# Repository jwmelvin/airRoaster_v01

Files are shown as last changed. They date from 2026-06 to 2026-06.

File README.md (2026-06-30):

# airRoaster

ESP32-based controller for a hot-air coffee roaster. Controls a heating element and fan independently via two [RBDimmer DimmerLink](https://www.rbdimmer.com/docs/dimmerlink-I2CCommunication) I2C AC dimmers, with a WebSocket interface for remote control and an OLED display for local status.

---

## Hardware

| Component | Details |
|---|---|
| MCU | ESP32-S3 Feather with 4MB Flash 2MB PSRAM, https://www.adafruit.com/product/5477 (any ESP32 variant with I2C and WiFi) |
| Display | FeatherWing OLED - 128x64 OLED, https://www.adafruit.com/product/4650 (SH1107 64×128 OLED), I2C address `0x3C` |
| Dimmer interface | RBDimmer DimmerLink, https://www.rbdimmer.com/docs/dimmerlink-overview, I2C address heat: `0x51`; fan: `0x52`, curve is set to mode `1` at startup. |
| Dimmers |Dimmers purchased from RobotDyn Official Store on AliExpress. "Dimmer AC module High Power for 40A 600V High Load, 1 Channel, 3.3V/5V logic"; "Dimmer AC module for 16A/24A 600V High Load, 1 Channel, 3.3V/5V logic with current load control" |
| Heater | from sdm2020_tools on eBay and listed as "1 set 230V 3600W 132.387 Heating Element & mica casing for hot air blower guns". Its power in my use is a little higher because I use 240V.|
| Blower | Ametek 116392-00 |

---

## Configuration

### WiFi credentials

Copy the credentials template and fill in your network details. This file is gitignored and should never be committed.

```
cp secrets.h.example secrets.h   # edit WIFI_SSID and WIFI_PASS
```

If `secrets.h.example` does not exist yet, create `secrets.h` manually:

```cpp
#pragma once
#define WIFI_SSID   "your_ssid"
#define WIFI_PASS   "your_password"
```

### Compile-time constants

| Constant | Default | Description |
|---|---|---|
| `DUTY_STEP` | `5` | Increment/decrement step for UP/DOWN commands (%) |
| `WS_PORT` | `81` | WebSocket server port |
| `DL_INIT_RETRY_DELAY_MS` | `500` | Delay between DimmerLink ready-check retries at startup (ms) |
| `IL_FAN_MIN` | `23` | Fan level below which heat is always 0 (both interlock modes) |
| `IL_FAN_FULL` | `30` | Fan level at or above which heat is fully unrestricted (soft mode) |
| `IL_HEAT_AT_MIN` | `30` | Heat cap (%) when fan is exactly at `IL_FAN_MIN` (soft mode) |

---

## Startup sequence

1. Display and I2C bus initialize
2. Both DimmerLink devices initialize — retried up to 3 times each (`DL_INIT_RETRY_DELAY_MS` apart); failures are logged. Dimmer init happens before WiFi to avoid missing the ready window at power-on.
3. ESP32 connects to WiFi (blocks until connected)
4. WebSocket server starts on port `81`
5. IP address is shown on the display

---

## Interfaces

### WebSocket (`ws://<device-ip>:81`)

The controller speaks two protocols on the same connection:

#### Artisan protocol (request/response)

Artisan polls the device on its sample interval. The controller responds with the current temperature readings.

**Request** (sent by Artisan):
```json
{"command": "getData", "id": 12345, "machine": 0}
```

**Response** (sent by controller):
```json
{"id": 12345, "data": {"BT": 195.3, "ET": 210.0}}
```

`BT` and `ET` are currently stubbed at `0.0` pending sensor integration. When sensors are added, populate the `btTemp` and `etTemp` globals in the firmware.

#### Plain-text commands

Artisan sliders and any other client send plain-text commands. Token delimiters are space, comma, semicolon, or equals sign. Commands are case-insensitive.

| Command | Example | Description |
|---|---|---|
| `OT1 <value>` | `OT1 60` | Set heat level (0–100%) |
| `OT1 UP` | `OT1 UP` | Increase heat by `DUTY_STEP` |
| `OT1 DOWN` | `OT1 DOWN` | Decrease heat by `DUTY_STEP` |
| `OT2 <value>` | `OT2 50` | Set fan level (0–100%) |
| `OT2 UP` | `OT2 UP` | Increase fan by `DUTY_STEP` |
| `OT2 DOWN` | `OT2 DOWN` | Decrease fan by `DUTY_STEP` |
| `INLET <degC>` | `INLET 165` | Set inlet setpoint and engage closed-loop control (see [Inlet temperature control](#inlet-temperature-control)) |
| `INLET OFF` | `INLET OFF` | Disengage closed-loop control; heat holds at its current level |
| `PID` | `PID` | Report current PID gains, setpoint, and mode |
| `PID <kp ki kd>` | `PID 1.5 0.05 0` | Set PID gains live (for manual tuning) |
| `TUNE` | `TUNE` | Run an open-loop step test and suggest PI gains (see [Tuning](#tuning)) |
| `TUNE <pct>` | `TUNE 20` | Step test with a specific heat step (% points) |
| `TUNE ABORT` | `TUNE ABORT` | Cancel a running step test |
| `TUNE APPLY` | `TUNE APPLY` | Apply the last test's "tight" suggested gains |
| `FF` | `FF` | Report feedforward params and current value (see [Feedforward](#feedforward-airflow-compensation)) |
| `FF <k>` | `FF 0.0045` | Set the feedforward coefficient `ffK` directly |
| `FF AMB <degC>` | `FF AMB 24` | Set the ambient reference temperature |
| `FF CAL` | `FF CAL` | Auto-calibrate `ffK` from the current (steady) operating point |
| `FF OFF` | `FF OFF` | Disable feedforward (`ffK = 0`) |
| `STAT` | `STAT` | Report and reset the control-cadence jitter watch (worst late-fire, µs) |
| `IL` | `IL` | Toggle interlock mode between hard and soft (see [Fan interlock](#fan-interlock)) |
| `LOG` | `LOG` | Retrieve the error log (sent only to requesting client) |

Sending `OT1 <value>` (manual heat) at any time is an **instant override**: it
drops the controller out of closed-loop mode and applies the manual level.

All unsolicited messages use Artisan's push message envelope so any client can use a consistent format:

**Status broadcast** (sent to all clients on any state change, and to new clients on connect):

```json
{"pushMessage": "status", "data": {"heat": 60, "heatReq": 60, "fan": 50, "ilCap": 100, "ilSoft": false, "mode": "manual", "inSV": 0.0}}
```

| `data` field | Description |
|---|---|
| `heat` | Actual heat level applied to the dimmer (%) |
| `heatReq` | Requested heat level before interlock (%) |
| `fan` | Fan level (%) |
| `ilCap` | Current heat ceiling imposed by the interlock (0–100%); `0` means heat is fully blocked, `100` means unrestricted |
| `ilSoft` | `true` if soft (linear) interlock mode is active; `false` for hard (binary) mode |
| `mode` | `"manual"` (heat set directly by `OT1`), `"inlet"` (heat modulated by the closed loop), or `"tune"` (a step test is running) |
| `inSV` | Inlet setpoint (°C) in use when `mode` is `"inlet"` |

**Error broadcast** (sent to all clients when an error is logged):

```json
{"pushMessage": "error", "data": "DimmerLink 0x51 ERR_PARAM (0xFE)"}
```

**Log response** (sent only to the client that sent `LOG`):

```json
{"pushMessage": "log", "data": "DimmerLink 0x52 not ready after 3 tries"}
{"pushMessage": "log", "data": "no errors"}
```

### Serial (115200 baud)

Accepts the same command set as WebSocket, terminated by newline. Maximum command length is 32 bytes. `LOG` prints the error log to Serial, one entry per line prefixed with `[LOG]`.

---

## Fan interlock

The interlock prevents the heating element from running without adequate airflow. It is always active and has two modes, toggled with the `IL` command (default: hard).

### Hard mode (default)

Binary cutoff: heat is forced to `0` when `fan < IL_FAN_MIN`, and fully unrestricted otherwise.

### Soft mode

Linear ramp between two breakpoints:

| Fan level | Heat cap |
|---|---|
| `< IL_FAN_MIN` (23) | 0% (blocked) |
| `IL_FAN_MIN` (23) | `IL_HEAT_AT_MIN` (30%) |
| `IL_FAN_FULL` (30) | 100% (unrestricted) |
| `> IL_FAN_FULL` | 100% |

Between 23 and 30 the cap is interpolated linearly, so heat scales with airflow rather than snapping on at a threshold.

In both modes:
- `heatReq` tracks what the user commanded
- `heat` reflects what is actually applied after capping
- Heat adjusts automatically whenever the fan level changes
- The interlock is re-evaluated every loop iteration

---

## Inlet temperature control

The controller can hold a target **inlet** temperature itself, closing the loop
on-device instead of relying on Artisan's 1 Hz command cycle. This is a
switchable mode layered on top of manual heat control.

### Modes

| Mode | How heat is set |
|---|---|
| `manual` (default) | Heat is whatever `OT1` last commanded |
| `inlet` | Heat is modulated by a PI(D) loop to hold the inlet setpoint |

- `INLET <degC>` engages `inlet` mode (bumpless — no heat step on engage) and
  sets the setpoint. Sending `INLET` again just retargets the setpoint and keeps
  the integrator, so a gradually-changing setpoint during a roast (e.g. driven
  from an Artisan background profile) does not reset the loop.
- `INLET OFF` returns to `manual`, holding heat at its current level.
- `OT1 <value>` is an instant manual override (drops back to `manual`).

### Control law

`controlStep()` runs on a fixed cadence (`CONTROL_PERIOD_MS`, default 250 ms)
from the main loop. The law is intentionally isolated in that one function
operating on shared globals — the *seam* that lets it move to a dedicated
FreeRTOS task later without changing the math (see `work.md`). It is currently
**cooperative** (single-core): adequate for a thermal plant with tens-of-seconds
time constants, and free of the cross-core I²C/SPI bus contention a dedicated
control task would introduce. The `STAT` command reports the worst observed
control-step timing jitter as evidence on whether a dedicated core is ever
warranted.

Key properties:
- **Derivative on measurement** (no setpoint-change kick), low-pass filtered.
- **Back-calculation anti-windup** against the *actually applied* heat — i.e.
  post-interlock — so the fan interlock capping heat does not wind up the
  integrator.
- Starts **PI-only** (`Kd = 0`); the inlet thermocouple is noisy near the
  dimmers (see [hardware/emi.md](hardware/emi.md)), so derivative is added only
  after the plant is characterized.

### Tuning

> ⚠️ The default gains (`pidKp`/`pidKi`/`pidKd` in the firmware) are **untuned
> placeholders** and are not expected to control well. Characterize the plant
> with `TUNE` (below) and apply gains before relying on closed-loop control.

- `PID` reports the current gains, setpoint, and mode.
- `PID <kp> <ki> <kd>` sets the gains live over WebSocket/serial, so you can tune
  without recompiling.

#### Autotune (`TUNE`)

`TUNE` runs an **open-loop step test**: it holds the current heat to measure a
baseline inlet temperature, applies a heat step, records the response, fits a
first-order-plus-dead-time (FOPDT) model (two-point 28.3%/63.2% method), and
suggests PI gains via the SIMC rule at two robustness levels.

**Procedure**

1. Set the fan to a representative level (your normal roasting range) and a
   moderate heat, and let the inlet temperature settle.
2. Send `TUNE` (default step) or `TUNE <pct>` (e.g. `TUNE 20`). The display shows
   `Tuning...` and `mode` becomes `tune`.
3. The test holds baseline (~8 s), steps heat up, and watches until the response
   flattens (or a 180 s cap). Heat returns to baseline and mode returns to
   `manual` automatically.
4. The result is broadcast as a `tune` push message:
   ```json
   {"pushMessage":"tune","data":{"ok":true,"fan":57,"step":15,"dT":42.3,
     "Kp":2.82,"tau":18.5,"theta":3.2,
     "tight":{"kp":1.97,"ki":0.13},"cons":{"kp":0.79,"ki":0.05}}}
   ```
   - `Kp` (°C/%), `tau`, `theta` (s) are the identified plant model.
   - `tight` is the brisker suggestion (tracking-first); `cons` is more
     conservative. Start with `tight`, fall back to `cons` if it overshoots or
     oscillates.
5. Apply gains with `TUNE APPLY` (uses the `tight` set) or `PID <kp> <ki> <kd>`
   to enter a chosen pair manually. Then `INLET <degC>` to run closed-loop.

**Safety / aborts.** The step goes through the fan interlock, so inadequate
airflow aborts the test (`interlock capped step`). It also aborts on over-temp
(`> 280 °C` inlet) and on any `OT1`/`INLET`/`TUNE ABORT`. A failed fit reports
`{"ok":false,"reason":...}`.

Because plant gain and time constant vary with airflow, run `TUNE` at the center
of your fan range (~57). The feedforward below — not the PID gains — is the main
mechanism for robustness against airflow changes.

### Feedforward (airflow compensation)

Steady-state heater power scales with airflow × temperature rise, so the
controller adds a feedforward term:

```
heat_ff = ffK · fan · (SV − ambient)
```

summed into the control output. The PID then only has to trim the residual. The
payoff is **airflow rejection**: when the fan changes mid-roast, `heat_ff` moves
*immediately* in proportion, instead of waiting for the inlet temperature to
drift and the integrator to catch up. One coefficient covers the narrow fan band.

Feedforward is **off by default** (`ffK = 0`). To set it up:

1. Stabilize the roaster in closed loop (or manual) at a representative fan and
   inlet temperature.
2. Send `FF AMB <degC>` with your ambient temperature (once), then `FF CAL`. This
   derives `ffK` from the current operating point:
   `ffK = heat / (fan · (inlet − ambient))`.
3. `FF` reports the result; `FF <k>` sets the coefficient by hand; `FF OFF`
   disables it.

With feedforward calibrated, the integrator settles near zero and the loop
rejects fan-speed changes largely through the feedforward path. Reported as an
`ff` push message: `{"ffK":0.00451,"amb":24.0,"ff":38.7}`.

---

## Commissioning

Bring the controller up in this order. Every step after the flash is a command
sent over WebSocket — the console page at [artisan/dashboard.html](artisan/dashboard.html)
has a **Commissioning sequence** panel that walks these steps with the value
fields prefilled.

1. **Flash.** With the board connected, run `./verify.sh upload` on the host.
2. **Sanity.** Stay in `manual`; confirm sensors, OLED, and Artisan still behave.
   After a few minutes send `STAT` to read control-cadence jitter — this is the
   evidence on whether the cooperative single-core design holds (expect
   single-digit ms).
3. **Characterize.** Set the fan to the center of your range (`OT2 57`) and a
   moderate heat (`OT1 40`), let the inlet temperature settle, then run `TUNE`.
   Eyeball the reported `dT`/`Kp`/`tau`/`theta` for sanity.
4. **Apply gains.** `TUNE APPLY` uses the `tight` suggestion; if it looks twitchy,
   enter the `cons` set by hand with `PID <kp> <ki> <kd>`.
5. **Calibrate feedforward.** Still steady, send `FF AMB <ambient>` then `FF CAL`.
6. **Close the loop.** `INLET <degC>` near the current inlet temp (bumpless), then
   nudge the setpoint and watch tracking.
7. **The real test.** With the loop holding, deliberately change fan speed and
   confirm the inlet temperature barely moves — that is the feedforward earning
   its keep. Tune gains from there.

## OLED display layout

```
+--------------------------------+
|  airRoaster vX.Y.Z             |  ROW1 (firmware version)
|  Heat: 60        Req: 60       |  ROW2
|  Fan: 50                       |  ROW3
|  IL:H ok                       |  ROW4 (interlock status — see below)
|  Inlet SV:165                  |  ROW5 ("Inlet: off" in manual mode)
|  192.168.1.42                  |  ROW6 (IP address or "No WiFi")
|                                |  ROW7
|  B:198.4 E:212.0 I:264.1       |  ROW8 (BT / ET / inlet temps, °C)
+--------------------------------+
```

ROW4 interlock status values:

| Display | Meaning |
|---|---|
| `IL:H ok` | Hard mode, fan above threshold, heat unrestricted |
| `IL:S ok` | Soft mode, fan above `IL_FAN_FULL`, heat unrestricted |
| `IL:S cap=N%` | Soft mode, fan in ramp zone, heat capped at N% |
| `IL:H BLOCKED` | Hard mode, fan below `IL_FAN_MIN`, heat forced to 0 |
| `IL:S BLOCKED` | Soft mode, fan below `IL_FAN_MIN`, heat forced to 0 |

---

## Error logging

Errors are stored in a RAM-only circular buffer (8 entries × 64 chars). No flash writes are performed. The log is lost on reboot.

Errors are generated for:
- DimmerLink not ready at startup (after 3 retries)
- DimmerLink error register non-zero after a write (`ERR_SYNTAX`, `ERR_NOT_READY`, `ERR_INDEX`, `ERR_PARAM`, or unknown code)
- DimmerLink error register polled every 5 seconds during operation

Retrieve the log at any time by sending `LOG` over WebSocket.

---

## Artisan integration

A ready-to-import Artisan settings file is provided at `artisan/airRoaster.aset` in this repo.

**Before importing**, open the file in a text editor and replace `<device-ip>` with your ESP32's IP address (shown on the OLED at startup). Then import via **File › Load Settings** in Artisan.

| Artisan setting | Value |
|---|---|
| Device | WebSocket (id 111) |
| Host | your ESP32's IP |
| Port | 81 |
| Input 1 → BT | `BT` node — bean RTD (the connected probe) |
| Input 2 → ET | `ET` node — second RTD (no probe yet; reads ~0) |
| Input 3 → IN | `IN` node — inlet thermocouple |
| Slider 0 | Fan — sends `OT2;<value>` |
| Slider 1 | Heat — sends `OT1;<value>` |

**Configuring the WebSocket inputs.** In Artisan, under **Config › Port ›
WebSocket**, set the input node names to match the firmware's JSON fields:
**Input 1: `BT`, Input 2: `ET`, Input 3: `IN`** (i.e. `channel_nodes=BT, ET, IN`
in the `.aset`). The node names just select which JSON field feeds each curve.

If a channel reads 0 °C / 32 °F while live data appears on a *different* curve,
the cause is almost always the **firmware** reading the wrong board for that
channel — confirm `CS_RTD_BT` points at the MAX31865 the bean probe is actually
wired to (see [hardware/pins.md](hardware/pins.md)). It is *not* an Artisan
channel-order issue.

The `ET` channel returns `0.0` until a second RTD probe is wired and
`RTD_ET_ENABLED` is set to `1` in the firmware.

### Adding more sensors

Artisan supports up to 10 channels via WebSocket: 2 on the main device plus 2 per extra device (max 4 extra devices), all pointing at the same `ws://<device-ip>:81`. The 10-channel ceiling is a total across the main device and all extra devices combined.

**To add channels** (firmware):
1. Add a global float for the new sensor
2. Extend the `data` object in `handleArtisanRequest()`:
   ```cpp
   snprintf(buf, sizeof(buf),
            "{\"id\":%s,\"data\":{\"BT\":%.1f,\"ET\":%.1f,\"inlet\":%.1f}}",
            idStr, btTemp, etTemp, inletTemp);
   ```

**To expose new channels in Artisan** (up to 10 total):
- For the first 2 channels beyond BT/ET, add node names to `channel_nodes` in the main device's `.aset` entry
- For additional pairs, add WebSocket extra devices in Artisan pointing at the same `ws://<device-ip>:81`, each with its own `channel_nodes` pair — they connect as additional clients and `handleArtisanRequest()` serves them all from the same `data` object with no firmware changes needed

**Beyond 10 channels:** a second WebSocket server on a different port would be required, as Artisan's framework caps at 10 channels per connection group.

---

## Dependencies

Install via Arduino Library Manager:

- [Adafruit GFX Library](https://github.com/adafruit/Adafruit-GFX-Library)
- [Adafruit SH110X](https://github.com/adafruit/Adafruit_SH110x)
- [WebSockets by Markus Sattler](https://github.com/Links2004/arduinoWebSockets)

---

## License

MIT — see [LICENSE](LICENSE).

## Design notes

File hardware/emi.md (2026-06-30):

# EMI / Sensor Noise — diagnosis and mitigation

How the AC dimmers couple noise into the temperature sensors, what's been done
about it, and what's left. Referenced from the sensor code in
[`../airRoaster.ino`](../airRoaster.ino) (`serviceRtd()` and the
robust-read constants).

---

## TL;DR — priority actions

| # | Action | Side | Status |
|---|---|---|---|
| 1 | Firmware tolerance: glitch-reject, debounce, hold-last-good | software | **done** (v0.2.0) |
| 2 | VIN–GND decoupling at each MAX31865 board (10 nF + 100 nF) | sensor | **done** |
| 3 | RC filter (100 Ω + 10 nF) on each RTD lead | sensor | **done** (helps lead pickup, not the reference path) |
| 4 | Twist each dimmer→load pair (line + return together) | source | **done** |
| 5 | Foil + copper-mesh shield on load runs, single-end grounded at enclosure | source | **done** |
| 6 | Dedicated earth bond to roaster body / enclosure (0.2 Ω) | grounding | **done** (was ~2 Ω) |
| 7 | Relocate 12→5 V converter below the divider | supply | **done** |
| 8 | Caps on R-78W output + input, and 5 V point-of-load (see below) | supply | **in progress** |
| 9 | SPI: shorten runs + 33 Ω series resistors at the Feather | sensor | **todo** |
| 10 | Clamp-on / toroid ferrite at the dimmer end of each load cable | source | **optional** |

The source-side and grounding work (4–7) is done. Remaining: finish the supply
decoupling (8) and tidy the SPI wiring (9), which is now the weakest link.

---

## Symptom

The connected PT1000 RTD (MAX31865) periodically stops reporting new values
during a roast and, before the firmware fix, would drop to 0 °C (= 32 °F in
Artisan). The K-type thermocouple (MAX31855) on the same SPI bus is unaffected.

Representative fault log (from `LOG` over WebSocket — see
[`../artisan/dashboard.html`](../artisan/dashboard.html)):

```
MAX31865 ET fault: 0x60   <- most common
MAX31865 ET fault: 0x64
MAX31865 BT fault: 0x08
```

A roast log (`airRoaster_14.alog`) showed the working RTD dropping out for
9–21 s at a time, several times between 3 and 7 minutes in.

---

## Fault-code decoding (MAX31865 fault register, 0x07)

| Bit | Mask | Meaning |
|-----|---|---|
| D7 | 0x80 | RTD resistance above High Fault Threshold |
| D6 | 0x40 | RTD resistance below Low Fault Threshold |
| D5 | 0x20 | REFIN− > 0.85 × VBIAS |
| D4 | 0x10 | REFIN− < 0.85 × VBIAS (FORCE− open) |
| D3 | 0x08 | RTDIN− < 0.85 × VBIAS (RTD− / FORCE− open) |
| D2 | 0x04 | Overvoltage / undervoltage on an analog input |

Observed:

- **`0x60` = D6 + D5** — low RTD reading **+ reference low-side (REFIN−) pulled high.**
- **`0x64` = D6 + D5 + D2** — same, **plus an input transient outside the valid window.**
- **`0x08` = D3** — RTD− effectively open. This came from the *unconnected*
  board (no probe); it is expected and is gated off in firmware. The single
  connected probe is the **BT** (bean) probe; the no-probe board is **ET** and is
  disabled via `RTD_ET_ENABLED`.

The **D2 bit in `0x64` is the tell**: it fires only when an input briefly swings
outside its valid range — the fingerprint of an *injected transient*, not a
steady wiring fault. And **D5 places the disturbance in the reference path**
(the 4300 Ω reference resistor / VBIAS network), which is *internal to the
board* — not on the probe leads.

---

## Diagnosis

**Key clue: the thermocouple never faults, but the RTD does.** If this were
generic SPI-bus corruption or a dirty 3.3 V/5 V rail, both SPI devices would
suffer. They don't. That rules out "the whole bus is noisy" and points at what
makes the MAX31865 different:

1. It makes a **ratiometric** measurement against VBIAS through a tiny bias
   current. Disturb VBIAS or the reference divider and the reading moves.
2. It runs **analog fault comparators** (REFIN−, RTDIN−, over/under-voltage)
   continuously. A fast transient can trip a comparator mid-conversion even when
   the underlying ADC value would have been fine.

The phase-cutting dimmers (TRIAC fires partway through each mains half-cycle)
emit sharp broadband transients twice per cycle. These couple into wiring by
both magnetic (di/dt through load-wire loop area) and electric (dv/dt) fields.
The MAX31865's reference circuit is the susceptible victim.

**Not correlated with heat level** — confirmed in testing. That fits, because
the **fan dimmer runs continuously** through a roast (same RBDimmer module),
so its transients are present regardless of the heater setting. Both dimmers
are equal suspects; don't fixate on the heater.

### Why the lead RC filters didn't fully fix it

The 100 Ω + 10 nF filters on the RTD **leads** address pickup on the RTD wires
(the RTDIN path). But the dominant `0x60`/`0x64` faults are in the **REFIN /
VBIAS** path, which is on the board and not reachable from the leads. So the
lead RC is correct and worth keeping (it protects against RTDIN-side faults and
helps the open-lead case), but it cannot suppress the reference-path noise — which
is why dropouts persisted after adding it.

### Note on the 50/60 Hz notch filter

The MAX31865 has a selectable 50/60 Hz notch (Adafruit library default 60 Hz,
correct for US mains). It rejects *mains-frequency* pickup but **not** the
broadband dimmer-edge transients, so it is not the fix here — but it is set
correctly and should stay at 60 Hz.

---

## What's been done

### Software (v0.2.0)

`serviceRtd()` in [`../airRoaster.ino`](../airRoaster.ino) makes the
read robust instead of trusting a single fault byte:

- **Same-cycle glitch rejection** — two reads per cycle; if they disagree by
  more than `RTD_READ_DISAGREE_C` (2 °C) the SPI frame was likely corrupted, so
  the value is held and retried next cycle.
- **Plausibility window** — a reading is accepted only if it falls between
  `RTD_VALID_MIN_C` (−20 °C) and `RTD_VALID_MAX_C` (600 °C); a transient fault
  flag on an otherwise in-range value is ignored.
- **Debounce** — a channel is only declared faulted after `SENSOR_FAULT_DEBOUNCE`
  (4) consecutive bad reads, so brief transients don't blank the curve.
- **Hold-last-good** — during a fault the global keeps its last valid value
  rather than dropping to 0 °C, so Artisan sees a momentary hold (much better for
  the curve and RoR than a spike to 32 °F).
- **Converter recovery** — `clearFault()` is followed by re-enabling bias and
  auto-convert (clearing the fault resets config bits, which would otherwise stop
  conversions).
- **Rate-limited logging** — repeated faults are logged at most every
  `SENSOR_REFAULT_LOG_MS` (5 s) so the 8-entry error log isn't flooded.

This makes the channel ride through brief EMI events regardless of source, but it
is *tolerance*, not a cure — the hardware items below reduce the events
themselves.

### Hardware (sensor side)

- **VIN–GND decoupling** at each MAX31865 board input — 10 nF + 100 nF,
  stiffening the supply feeding VBIAS.
- **RC filter** (100 Ω series + 10 nF to GND) on each RTD lead — two per board,
  on RTD+ and RTD−. RC ≈ 1 µs, well inside the MAX31865's tolerance.

### Hardware (source + grounding + supply)

- **Twisted load pairs** — each dimmer→load line+return twisted together to
  collapse loop area (magnetic emission).
- **Foil + copper-mesh shield** over the load runs, **single-end grounded at the
  enclosure** (stops short of the grounded roaster body to avoid a ground loop;
  see §3 under *Source suppression* for the foil+mesh and single-end rationale).
- **Dedicated earth bond** added — roaster body / enclosure to incoming earth is
  now **0.2 Ω** (was ~2 Ω). Improves both fault safety and the shield's ground
  reference.
- **12→5 V converter (R-78W) relocated below the divider**, moving the switching
  node to the mains side; only the filtered 5 V now crosses to the sensors.

### Considered but not feasible

- **Cap directly across the reference resistor (REFIN+ / REFIN−)** would target
  the `0x60` path directly, but the SMD pads are too small/precise to add
  reliably by hand. Abandoned in favour of supply decoupling + source
  suppression.

---

## Capacitor summary

Consolidated list of every decoupling/filter cap in the system. The first three
rows are installed; the supply-rail rows are the remaining additions.

| Location | Caps | Purpose | Status |
|---|---|---|---|
| Each RTD lead → GND | 10 nF (+ 100 Ω series) | RTD-lead pickup filter (RTDIN path) | installed |
| Each MAX31865 VIN/3V3 → GND | 10 nF + 100 nF | board supply decoupling at VBIAS | installed |
| **R-78W 5 V output** | **100 µF electrolytic (low-ESR) + 100 nF ceramic** | absorb switching ripple at the source | add |
| **R-78W 12 V input** | **10 µF** | switcher input decoupling + stops switching current conducting back up the 12 V line | add |
| **5 V arrival, top side near Feather** | **47–100 µF bulk** | point-of-load; catches noise picked up crossing the divider | add |
| 3.3 V distribution node (optional) | 10 µF bulk | rounds out the 3.3 V rail (likely already covered by the Feather LDO) | optional |

Notes:
- Place the R-78W caps **as close to the converter pins as the terminal block
  allows** — lead length undoes the benefit.
- The 5 V point-of-load cap matters specifically because the converter now lives
  below the divider, so the 5 V output travels across to the sensors: filter hard
  at the source **and** again where it arrives.

## SPI wiring

The remaining weak link. The SPI bundle from the three breakouts to the Feather
is long and the signals aren't paired with grounds. **Caps are not the right tool
here** — capacitance on SPI lines rounds the edges and can hurt signal integrity
at the clock rate. Instead, in priority order:

1. **Shorten the runs** (SCK shortened already) and **twist each signal with a
   ground return**, or run the group flat against the grounded panel.
2. **33 Ω series resistors** on SCK / MOSI / MISO **at the Feather end** — damps
   ringing; the closest thing to a component-level fix.
3. The firmware glitch-rejection (v0.2.0) already tolerates the occasional
   corrupted frame, so the SPI wiring doesn't have to be perfect.

---

## Source suppression — reference

> **Status:** items 1, 3, and 6 below are **done** (twisted pairs, foil+mesh
> shield single-end grounded, dedicated 0.2 Ω earth bond). Ferrites (2), the
> blower brush caps (4), and the snubber (5) remain optional. Kept here as the
> technical reference for why each measure works.

The dimmer→fan and dimmer→heater load cables carry the phase-cut current and are
the primary emitters. Attacking the source helps every victim at once.

### 1. Twist each load pair — biggest free win

Radiated magnetic field is proportional to the **loop area** between the
outgoing conductor and its return. Route each load's line and neutral **together
as a tight pair and twist them**; this collapses the loop area and dramatically
cuts magnetic emission. Make sure the return actually runs alongside the switched
conductor rather than taking a separate path.

### 2. Ferrites on the load cables

Add a **clamp-on ferrite or toroid at the dimmer end of each load cable** (and
optionally where the cable exits the enclosure). Pass **both conductors of that
load through the same core** so the 60 Hz fields cancel and only the
high-frequency common-mode component is choked. A few turns through a toroid
beats a single pass-through clamp. Cheap, reversible, no effect on the 60 Hz
power.

### 3. Shield the external runs

Twisting handles the magnetic field; a grounded shield handles the electric
field. Do both.

**Foil + mesh (as built).** This is the standard foil-braid construction:
- **Foil** gives ~100 % coverage and closes the apertures for higher-frequency
  content. Overlap wraps ≥50 %. Watch for foil tape with *non-conductive*
  adhesive — only the exposed face conducts, so the mesh over it ties it together.
- **Copper mesh** provides the low-impedance ground-drain path and mechanical
  robustness foil lacks. **Fairly open mesh is fine** at the frequencies that
  matter here — the holes are tiny vs. wavelength, so E-field attenuation stays
  good. Multiple wraps raise effective coverage and lower shield resistance; two
  layers is plenty.
- Foil and mesh must be in **electrical contact** so they bond as one shield.

**Shield grounding — one end, at the enclosure (source).** The cable is
electrically short at these frequencies, so single-end termination gives
essentially full shielding without a floating-stub penalty, and it avoids a
ground loop between the enclosure earth and the **separately-grounded roaster
body**. Ground at the *source* (enclosure) end so intercepted noise current
returns near the dimmer. **Stop the shield just short of the body** and insulate
the floating end so it can't contact the body (which would sneak-ground the
second end) or a live conductor.

Alternatively, **shielded mains-rated cable** (e.g. SY/CY screened flex) or
**grounded metal conduit** achieves the same thing in one component.

### 4. Blower brush noise (separate source)

The Ametek 116392-00 is a brushed universal motor, so it generates its own
broadband RF from brush arcing, independent of the dimmer. Ferrites on the motor
leads (item 2) help. Motor-suppression X/Y caps across the brushes are the
classic fix but interact with the TRIAC dimmer — add cautiously, ferrites first.

### 5. Snubber across the dimmer output (advanced, optional)

An RC snubber (≈100 Ω + ~0.1 µF X-rated) across the dimmer output softens the
switching edge and reduces broadband emission. **Caveat:** the RBDimmer modules
may already include one; an added snubber passes a little leakage current when
"off" and can affect low-end dimming. Try the wiring measures first.

### 6. Grounding discipline — done

The enclosure/back-panel is **bonded to AC earth**, with a **dedicated bond now
at 0.2 Ω** (was ~2 Ω), and shields/panel return to a single earth point. HF
currents have a defined low-impedance path and don't circulate through signal
ground.

### Supply side — R-78W (RECOM R-78W-0.5)

The 12 V→5 V converter is a switching regulator (~500 kHz). It has been
**relocated below the divider**, so its switching node sits on the mains side and
only the filtered 5 V crosses to the sensors. Decoupling caps (output bulk +
ceramic, input cap, and a 5 V point-of-load cap up top) are listed in the
[Capacitor summary](#capacitor-summary) — those are the remaining additions.

---

## Layout reference

- Low-voltage section is above the white divider; mains below. Dimmers are lower
  left (below the divider). The R-78W now sits **below** the divider, so its
  switching node is on the mains side and only the **filtered 5 V crosses** the
  divider to the sensors.
- Keep sensor cables (especially the RTD leads) flat against the grounded panel,
  short, and crossing any AC wiring at 90° rather than running parallel.
- See [`pins.md`](pins.md) for the full pin/bus map.

---

## Diagnostic workflow

1. Open [`../artisan/dashboard.html`](../artisan/dashboard.html) in a browser, connect to the
   ESP32 IP, and watch the live `error`/`log` stream during a roast.
2. Note which channel (BT/ET) and which fault codes appear, and whether they
   correlate with fan level, heat level, or are constant.
3. Decode codes with the table above. REFIN/over-voltage bits (D5/D2) ⇒ reference
   path / injected transient ⇒ source suppression + supply decoupling. RTDIN/open
   bits (D3/D4) ⇒ check leads, terminals, and the RC filter on that leg.
4. After each mitigation, compare dropout frequency/duration in the Artisan
   `.alog` to gauge improvement.

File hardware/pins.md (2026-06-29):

# Pin Usage — ESP32-S3 Feather (Adafruit 5477)

Arduino variant file: `adafruit_feather_esp32s3`

---

## I2C bus

SDA = GPIO 3 (A6), SCL = GPIO 4 (A7)
Pull-ups: 5 kΩ on-board; also exposed on STEMMA QT connector.

| Address | Device | Product |
|---|---|---|
| `0x3C` | SH1107 OLED | Adafruit 4650 FeatherWing |
| `0x51` | DimmerLink — heat | RBDimmer DimmerLink |
| `0x52` | DimmerLink — fan | RBDimmer DimmerLink |
| TBD (`0x76` or `0x77`) | BME688 env sensor | Adafruit 5046 (future) |

The BME688 connects via the STEMMA QT port — no extra wiring needed.

---

## SPI bus

SCK = GPIO 36, MOSI = GPIO 35, MISO = GPIO 37

| GPIO | Feather label | Firmware define | Device | Role |
|---|---|---|---|---|
| 36 | SCK | — | shared | SPI clock |
| 35 | MOSI | — | shared | SPI data out |
| 37 | MISO | — | shared | SPI data in |
| 10 | D10 / A11 | `CS_RTD_BT` | MAX31865 (Adafruit 3648) | Bean temp PT1000 |
| 9 | D9 / A10 | `CS_RTD_ET` | MAX31865 (Adafruit 3648) | Exhaust/ET PT1000 |
| 8 | A5 | `CS_TC_IN` | MAX31855 (Adafruit 269) | Inlet K-type thermocouple |

---

## Reserved / do not use

| GPIO | Label | Reason |
|---|---|---|
| 3 | SDA / A6 | I2C in use |
| 4 | SCL / A7 | I2C in use |
| 7 | — | I2C power control (managed by board) |
| 13 | D13 | Built-in red LED |
| 21 | — | NeoPixel power enable |
| 33 | — | NeoPixel data |
| 35 | MOSI | SPI in use |
| 36 | SCK | SPI in use |
| 37 | MISO | SPI in use |

---

## Free GPIOs

| GPIO | Feather label |
|---|---|
| 5 | A8 |
| 6 | A9 |
| 11 | A12 |
| 12 | A13 |
| 14 | A4 |
| 15 | A3 |
| 16 | A2 |
| 17 | A1 |
| 18 | A0 |
| 38 | RX (Serial1) |
| 39 | TX (Serial1) |
| 42 | SS (default SPI SS, unused) |

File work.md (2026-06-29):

# Development plan

## inlet-temp control

### framing

The airRoaster now measures inlet temperature, which is a primary process variable. The current system relies on external commands to regulate the heater to maintain a desired inlet temperature. That suffers from the slower reporting cycle by which Artisan receives temperature updates and sends heater commands (1 Hz). Improvement (tighter control) can come from internalizing the control loop. It will also allow flexible control strategies that Artisan may not.

### objectives

Develop a switchable operating mode that accepts "inlet" commands to set the desired inlet temperature, and implements feedback control from the measured inlet temp to modulate the heater with the tightest possible control. The control strategy and tuning should prioritize robustness against flow variation (e.g., from external fan-speed changes). Generally, the inlet setpoint will change gradually during a roast, with large transitions happening only at the start of a roast. 

### design considerations

- as an initial gate, consider whether this change (or other project attributes) would favor moving from the Arduino environment to ESP-IDF (https://docs.espressif.com/projects/esp-idf/en/v6.0.1/esp32s3/index.html)

- one reason for that potential migration is that the microcontroller for this project, ESP32-S3, has dual cores and the temperature-measurement-and-control aspects might benefit from separating them from the interface (WiFi, websocket, and OLED) aspects. I do not know if Arduino supports dual-core implementations but ESP-IDF does.

### constraints

- Operate the control loop with deterministic timing.
- Branch the project so that work can progress on this new capability without disturbing the current code.
- 

### references

- PID library for Arduino environment: https://github.com/br3ttb/Arduino-PID-Library
-- author's explanations: http://brettbeauregard.com/blog/2011/04/improving-the-beginners-pid-introduction/
-- explanation of the library's POM mode:  http://brettbeauregard.com/blog/2017/06/introducing-proportional-on-measurement/
-- and: http://brettbeauregard.com/blog/2017/06/proportional-on-measurement-the-code/ 

---

## plan (2026-06-29)

Branch: `feature/inlet-control`. Planning only at this stage — no firmware
written yet.

### Gate decision 1 — stay in Arduino, do NOT migrate to ESP-IDF (yet)

The two reasons floated for ESP-IDF (deterministic timing, dual-core
separation) are both achievable *inside the Arduino-ESP32 core*, which is
itself a thin layer over ESP-IDF + FreeRTOS:

- **Dual core is already available.** The Arduino `loop()` runs as a FreeRTOS
  task (`loopTask`) pinned to core 1; core 0 runs the WiFi/BT stack. We can
  create our own control task with `xTaskCreatePinnedToCore()` — no migration
  required.
- **Deterministic cadence is already available.** A dedicated FreeRTOS task
  using `vTaskDelayUntil()` (fixed wake period, not `delay()`) at a raised
  priority gives a jitter-bounded loop independent of WebSocket/OLED work.

Against migration: a port would have to replace the whole interface stack that
already works — `WebSocketsServer` (Links2004), `Adafruit_SH110X`/`GFX`,
`Adafruit_MAX31865`/`MAX31855`, `WiFi`. That is weeks of yak-shaving for no
control benefit the Arduino core can't deliver. **Recommendation: keep Arduino;
revisit ESP-IDF only if we later hit a concrete wall (e.g. needing TLS, OTA at
scale, or sub-millisecond ISR-level timing the Arduino core obstructs).**

### Gate decision 2 — control library

Use **Dlloydev/QuickPID** for the controller and **Dlloydev/sTune** for
characterization/autotune (same author, designed to interoperate, both
ESP32-clean, actively maintained — unlike br3ttb's original which is feature-
frozen). QuickPID adds what we need over the original: selectable
Proportional-on-Error / Proportional-on-Measurement *blend* (per Beauregard's
POM articles), multiple anti-windup modes, and a TIMER mode that fits a
fixed-cadence FreeRTOS task. sTune's open-loop **s-curve inflection** test
identifies a first-order-plus-dead-time (FOPDT) model in ~½τ — ideal for a
thermal plant and the basis for an operator-runnable tuning routine.

References vetted: br3ttb library still works but is the wrong long-term choice;
QuickPID + sTune supersede it. (Kilill's ESP-IDF fork is only relevant if we
ever migrate.)

### Actuator note (simplifies everything)

The heater is a phase-cut AC dimmer that already accepts a **continuous 0–100
level** over I²C (`setLevel(HEAT_ADDR, …)`). So the PID output maps *directly*
to heat level — no time-proportioning relay/PWM layer needed. The control
output path is just: `pidOutput → requestedHeatLevel → applyInterlock() →
setLevel()`.

### Control strategy — robustness against flow variation is the design driver

Airflow (fan level, possibly changed externally mid-roast) changes BOTH the
plant gain and the time constant of inlet temperature vs. heat: more flow ⇒
lower steady inlet temp for the same power AND a faster, shorter-τ response.
A single fixed PID tuned at one flow will be sluggish or unstable at another.
Three layers, in priority order:

1. **Feedforward from a static power map** `heat_ff = f(setpoint, fan)`.
   Steady-state heater power needed scales ~linearly with mass-flow ×
   (T_set − T_ambient). A small calibrated map gives most of the command
   instantly when fan changes; the PID only trims the residual. This is the
   single biggest robustness win and largely neutralizes flow disturbances
   before the feedback loop has to react.
2. **Gain scheduling on fan level — conditional.** Because fan level is a
   *known* input, gains *can* be scheduled across fan breakpoints and
   interpolated. But the actual operating band is narrow (50–65, mostly 55–60;
   see Operator decisions), so a single tune at the center is the starting
   point and scheduling is added only if band-edge validation needs it.
3. **Robust feedback tuning (IMC / lambda).** Tune via Internal-Model-Control
   (lambda) rules rather than Ziegler-Nichols: λ is an explicit
   robustness/speed knob (λ ≈ θ for brisk, 2–3θ for conservative). Pick λ on
   the conservative side and validate gain margin at the worst-case (lowest-
   flow, highest-gain) point. Use **Proportional-on-Measurement-leaning blend**
   so the occasional large setpoint step (roast start) doesn't cause overshoot,
   while gradual setpoint moves during the roast stay tight.

Supporting details:
- **Anti-windup** is mandatory: heat saturates at 0/100 *and* the fan interlock
  can cap it below the PID's request. The integrator must be clamped/back-
  calculated against the **actually-applied** heat (post-interlock), not the
  requested value, or it winds up whenever the interlock bites.
- **Derivative** on the inlet thermocouple: derivative-on-measurement + light
  low-pass (the TC is fast but noisy near the dimmers — see hardware/emi.md).
  Start PI-only; add D only if sTune shows it helps.
- **Bumpless transfer**: on engaging inlet mode, seed the integrator with the
  current heat level so there's no step; on disengaging, leave heat as-is.

### Mode + command design

New switchable closed-loop mode layered on the existing manual path:
- `INLET <degC>` — set inlet setpoint AND engage closed-loop mode (bumpless).
- `INLET OFF` — disengage, hold last heat (manual).
- Sending `OT1 <value>` (manual heat) auto-disengages inlet mode — gives the
  operator an instant manual override with no extra command.
- `TUNE` (operator routine) — run an sTune open-loop step at the *current* fan
  level, report identified K/τ/θ + suggested gains over WebSocket/serial, and
  optionally store them into the gain-schedule slot for that fan band. Operator
  repeats at low/med/high fan to populate the schedule.
- Status broadcast gains: `mode` (manual|inlet), `inSV` (setpoint), and the
  inlet temp is already published as `IN`.

Artisan drives the setpoint via a background profile (see the utility below,
which generates an `.alog` whose background curve becomes the inlet SV) or a
dedicated slider/event mapped to the `INLET` command — mirroring how OT1/OT2
sliders work today.

### Concurrency / timing architecture

- **Core 1 (interface task = Arduino `loop()`):** WebSocket, OLED, command
  parsing, WiFi servicing — unchanged, non-deterministic is fine here.
- **Core 0 (new `controlTask`, pinned, raised priority, `vTaskDelayUntil`):**
  read inlet TC → run QuickPID (TIMER mode) → apply feedforward + gain schedule
  → write heat through the interlock. Fixed cadence ~5–10 Hz (the TC + thermal
  plant don't justify faster; deterministic period matters more than rate).
- **Shared state** (setpoint, mode, fan level, heat level, gains) guarded by a
  small mutex or made atomic. Keep the critical section tiny.
- The other sensors (BT/ET RTDs) and their robust-read logic can stay on the
  interface cadence or move into the control task; decide during implementation.

### Architecture decision (resolved 2026-06-29)

After working through the FreeRTOS dual-core option: **cooperative single-core**
for v1, with the control law isolated in a `controlStep()` *seam* (operates only
on shared globals) so it can later lift into a pinned task unchanged. Rationale:
the ESP32-S3 has two I2C controllers and a spare SPI, so a lock-free dual-core
partition *is* possible (heat dimmer on `Wire1`/control core; OLED+fan+all
sensors/SPI on the interface core; cross-core state as 32-bit-atomic scalars) —
but it needs a hardware rewire (heat dimmer → `Wire1`) in the EMI-sensitive zone
and the plant's tens-of-seconds time constants don't require sub-10 ms
determinism. `STAT` reports a control-cadence jitter watch as the evidence that
would justify migrating later.

Also decided to implement a **compact inline PID** rather than QuickPID for the
loop itself — it gives exact control over back-calculation anti-windup against
the *post-interlock* applied heat, with no dependency to install/compile here.
sTune is still the intended tool for the `TUNE` step-test routine (phase 3).

### Phased work

1. ~~Scaffolding: `controlStep()` seam, fixed-cadence call from `loop()`,
   jitter watch.~~ **done (v0.3.0)** — cooperative, not a task.
2. ~~Closed-loop PI(D) with back-calculation anti-windup against post-interlock
   heat; `INLET`/`INLET OFF`/`OT1`-override mode switching with bumpless
   transfer; `PID` live-tuning + `STAT` commands.~~ **done (v0.3.0)** — gains
   are untuned placeholders.
3. ~~`TUNE` routine (open-loop step test) + reporting; FOPDT fit + SIMC PI
   suggestions.~~ **done (v0.4.0)** — implemented inline (two-point FOPDT fit,
   SIMC tight/conservative gains) rather than with sTune, for full control over
   step safety/abort and to stay dependency-free + compile-checkable here.
   Operator still needs to run it at center fan (~57) and spot-check 50 / 65.
4. Feedforward power map (2–3 points across 50/57/65) + lambda/IMC gains from
   step (3); add gain scheduling only if band-edge validation needs it. **next**
5. Validation roasts: step + ramp setpoints, deliberate mid-roast fan changes;
   measure tracking/overshoot/settling and confirm robustness. Tune λ.
6. ~~Docs: README control-mode section.~~ **done (v0.3.0)** — Artisan
   integration + `.aset` for driving the setpoint still to do in phase 4.

### Operator decisions (resolved 2026-06-29)

1. **Overshoot tolerance is generous; tracking is the priority.** ~5 s at
   +10–20 °F (≈ +5.5–11 °C) overshoot at roast start is acceptable. What
   matters most is tight *tracking* during the roast and good rejection of
   airflow changes. → Tune on the **brisk** side (smaller λ, ≈ θ–1.5θ);
   prioritize setpoint tracking + flow-disturbance rejection over startup-step
   overshoot suppression. The generous startup tolerance means we do **not**
   need a heavy Proportional-on-Measurement bias to tame the opening step — a
   light POM blend or even proportional-on-error is fine. Validate on the
   tracking/disturbance metrics, not the startup step.
2. **Fan operates in a narrow band: 50–65, usually 55–60.** This is small
   enough that the plant gain/τ won't swing much across it, so **full gain
   scheduling is likely unnecessary.** Revised approach:
   - Identify the plant once with sTune at the **center (~57)**, and tune a
     single robust PID there.
   - Keep the **feedforward power map** anyway — it's what gives fast rejection
     of mid-roast airflow changes (the stated priority), and over a 50–65 span
     it's nearly linear so a 2–3 point map (50 / 57 / 65) suffices.
   - Add gain scheduling **only if** step (5) validation shows the single tune
     degrades at the band edges. Spot-check sTune at 50 and 65 to confirm the
     model barely moves before deciding.
3. **`OT1` is an instant manual override** — confirmed. Any `OT1 <value>`
   immediately disengages inlet mode and applies the manual heat level.

# utilities

## Artisan profile generator so a background can drive SV through Inlet control parameter

python3 make_inlet_background.py --out bkgnd_001-base_330-550_5.30.alog --mode ror_endpoint --no-mirror --template bkgnd_001-base.alog \
--t_drop 330 \
--T_start 350 --T_drop 500 \
--ror_start 50

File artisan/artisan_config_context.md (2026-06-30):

# Artisan Configuration Context — airRoaster

## Goal

Configure Artisan to:
1. Read BT and ET from two Phidget temperature modules on a networked HUB5000
2. Send fan and heat control commands to an ESP32 roaster controller over WebSocket

---

## Hardware

| Device | Role |
|---|---|
| ESP32 (airRoaster firmware) | Roaster controller — controls heat and fan via I2C AC dimmers |
| Phidget HUB5000 | VINT hub, networked at `192.168.1.232` (also reachable as `hub5000.local`) |
| Phidget TMP1200 on HUB VINT port 0 | RTD input, PT1000 probe → **BT (bean temperature)** |
| Phidget TMP1101 on HUB VINT port 1 | 4-channel thermocouple input, K-type probe on channel 0 → **ET (exhaust temperature)** |

---

## ESP32 WebSocket Interface

- URL: `ws://<esp32-ip>:81`
- The ESP32 IP is shown on its OLED display at startup.

### Polling (Artisan → ESP32)

Artisan sends on its sample interval:
```json
{"command": "getData", "id": 12345, "roasterID": 0}
```

ESP32 responds:
```json
{"id": 12345, "data": {"BT": 0.0, "ET": 0.0}}
```
BT and ET are currently stubbed at 0.0 — real values come from Phidgets (see below).

### Control commands (Artisan sliders → ESP32)

Slider actions use Artisan's WebSocket `send()` syntax:

| Slider | Action string | Effect |
|---|---|---|
| Fan | `send("OT2;{}")` | Sets fan level 0–100% |
| Heat | `send("OT1;{}")` | Sets heat level 0–100% |

The firmware also accepts `send({{"command":"OT2","value":{}}})` JSON envelope format — both work.

### Status broadcast (ESP32 → all clients, unsolicited)

```json
{"pushMessage": "status", "data": {"heat": 60, "heatReq": 60, "fan": 50, "ilCap": 100, "ilSoft": false}}
```

| Field | Description |
|---|---|
| `heat` | Actual heat level sent to dimmer (%) |
| `heatReq` | Requested heat level before interlock (%) |
| `fan` | Fan level (%) |
| `ilCap` | Current heat ceiling from interlock (0=blocked, 100=unrestricted) |
| `ilSoft` | `true` = soft (linear ramp) interlock; `false` = hard (binary) interlock |

---

## Key References

- Artisan WebSocket protocol: https://artisan-scope.org/devices/websockets/
- Artisan Phidgets configuration: https://artisan-roasterscope.blogspot.com/2017/12/more-phidgets.html
- HUB5000 + dual single-channel modules setup (home-barista forum, post #7 by Rob W):
  > Since each VINT module delivers only one channel but Artisan's main device expects two,
  > use an Extra Device for the second module and remap its channel to ET via the symbolic
  > formula `Y3` in the Symb ET/BT tab.

---

## Artisan Configuration Steps

### 1. Main device (Config → Device → 1st tab "ET/BT")

- **Meter**: `Phidget TMP1200`
  - This provides BT from VINT port 0, PT1000.
  - The ET slot will be filled via symbolic remap from the extra device (see step 4).

### 2. Phidgets tab (Config → Device → 4th tab "Phidgets")

- **TMP1200**: VINT port `0`, channel `0`, RTD type `PT1000`
- **Network**: ✓ ticked, host `192.168.1.232`, port `5661`

### 3. Extra Devices tab (Config → Device → Extra Devices)

Add **one extra device**:
- Type: `Phidget TMP1101 4xTC`
- VINT port `1`, channel `0`, thermocouple type `K`
- Untick **LCD and curve for channel 2** (TMP1101 returns only one signal here)
- Untick **LCD and curve for channel 1** (data will be remapped to ET — no need to display it separately)

Add **one more extra device** (for WebSocket slider control):
- Type: `WebSocket` pointed at `ws://<esp32-ip>:81`
- Untick LCD and curve for both channels (BT/ET from this device are stubbed at 0.0 and ignored)
- Sliders send via this connection

### 4. Symb ET/BT tab (Config → Device → 2nd tab)

- **ET Y(x)**: `Y3`

`Y3` is the symbolic variable for channel 1 of the first extra device (the TMP1101), routing its reading into the main device's ET slot.

### 5. Sliders (Config → Events → Sliders)

| Slider | Action type | Command |
|---|---|---|
| Slider 0 (Fan) | WebSocket | `send("OT2;{}")` |
| Slider 1 (Heat) | WebSocket | `send("OT1;{}")` |

Both sliders send over the WebSocket connection to the ESP32.

---

## Firmware Fan Interlock (informational)

The ESP32 firmware enforces a fan interlock — heat is suppressed when fan is too low.
Two modes, toggled by sending `IL` over WebSocket or serial:

| Mode | Behaviour |
|---|---|
| Hard (default) | Heat = 0 if fan < 23%, else unrestricted |
| Soft | Heat linearly capped: 30% at fan=23%, 100% at fan≥30% |

The `ilCap` field in the status broadcast shows the current ceiling.

---

## Existing .aset file

A partially-configured Artisan settings file exists at `artisan/airRoaster.aset` in the firmware repo. It was originally configured with:
- WebSocket as main device (now should move to extra device / control only)
- Sliders using Serial action (now updated to WebSocket `send()`)
- Phidgets not yet configured

The .aset file needs to be updated to reflect the configuration described above.

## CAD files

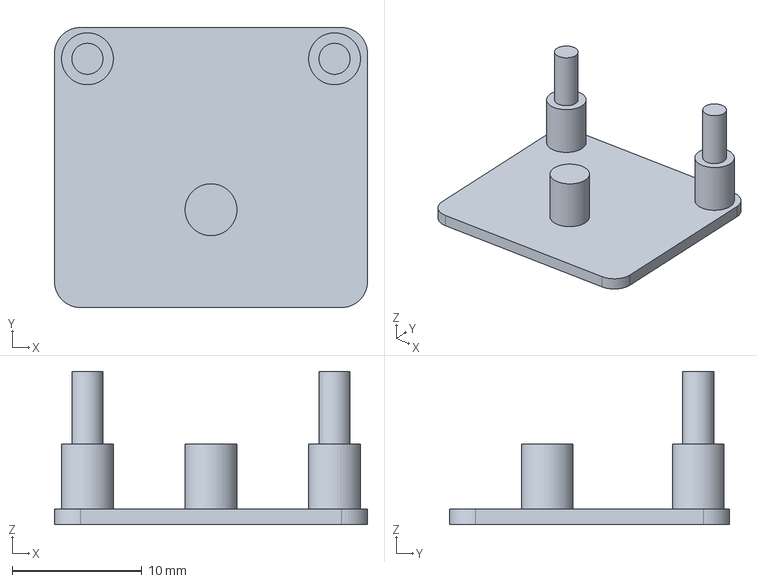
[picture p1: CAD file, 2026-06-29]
hardware/pcb_mounts/mount_3263_MAX31856.step
24.1 x 21.6 x 11.8 mm

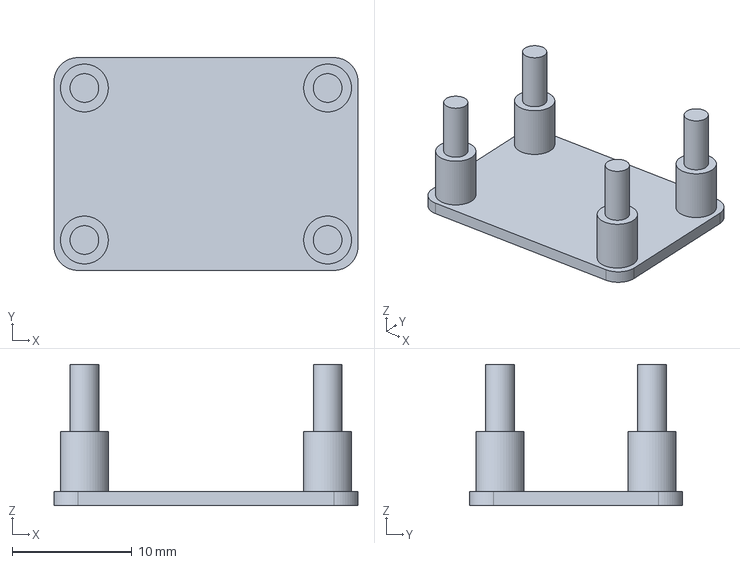
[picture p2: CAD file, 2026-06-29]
hardware/pcb_mounts/mount_5046_BME688.step
25.4 x 17.8 x 11.8 mm

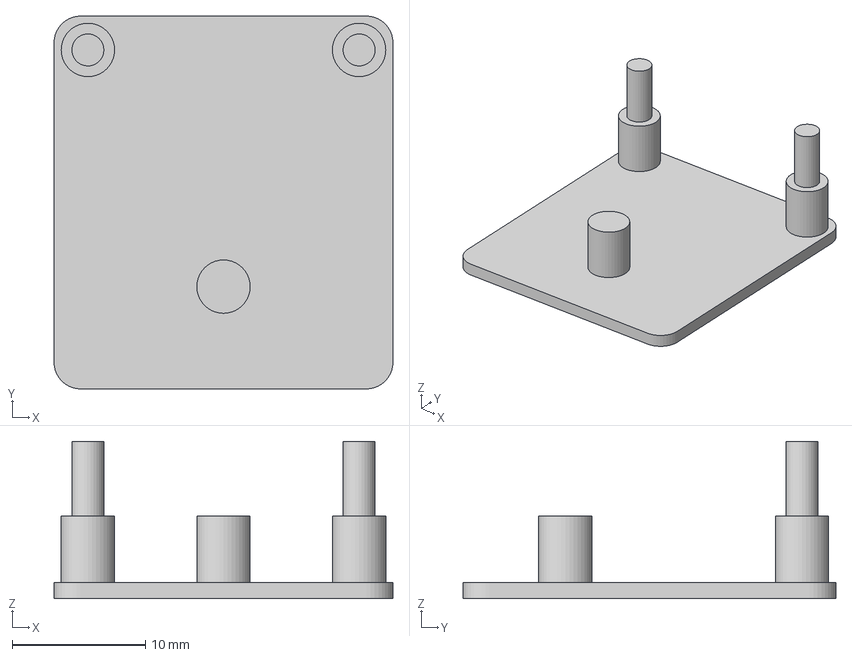
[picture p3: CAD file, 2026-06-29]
hardware/pcb_mounts/adafruit3648_mount.3mf
25.4 x 27.9 x 11.8 mm

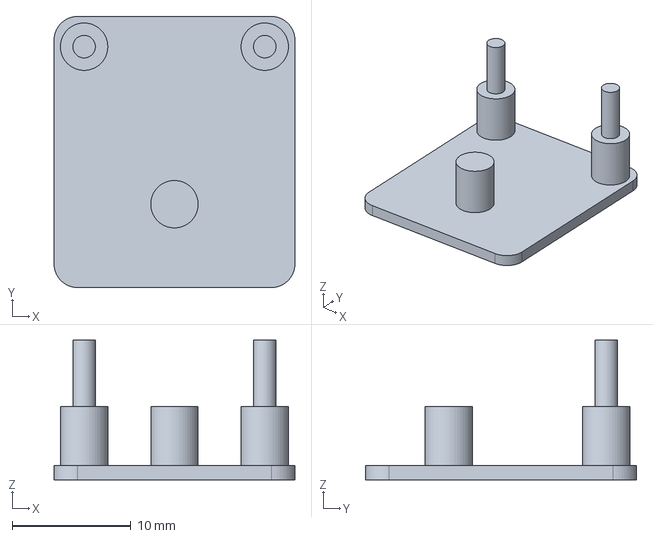
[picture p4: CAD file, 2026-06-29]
hardware/pcb_mounts/mount_269_MAX31855.step
20.3 x 22.9 x 11.8 mm

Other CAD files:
hardware/pcb_mounts/adafruit3263_mount.3mf
hardware/pcb_mounts/adafruit269_mount.3mf
hardware/pcb_mounts/mount_3648_MAX31865.step

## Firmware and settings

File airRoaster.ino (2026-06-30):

// ===========================================================================
// airRoaster — ESP32-S3 hot-air coffee roaster controller
//
// Firmware version: see FW_VERSION below.
// Change history:   bottom of this file.
// (Intentionally no "last edited" date in this header — it only goes stale.
//  The top entry of the version history is the real last-changed date.)
// ===========================================================================
#include <Wire.h>
#include <SPI.h>
#include <Adafruit_GFX.h>
#include <Adafruit_SH110X.h>
#include <WiFi.h>
#include <WebSocketsServer.h>
#include <Adafruit_MAX31855.h>
#include <Adafruit_MAX31865.h>

// ---------------------------------------------------------------------------
// Firmware identity
// ---------------------------------------------------------------------------
#define FW_VERSION  "0.5.0"

// ---------------------------------------------------------------------------
// WiFi credentials (defined in secrets.h — do not commit that file)
// ---------------------------------------------------------------------------
#include "secrets.h"

// ---------------------------------------------------------------------------
// Sensor SPI chip-select pins  (assign free GPIOs to suit your wiring)
// ---------------------------------------------------------------------------
#define CS_RTD_BT   10   // MAX31865 (product 3648) — bean temp RTD (connected probe)
#define CS_RTD_ET   9    // MAX31865 (product 3648) — exhaust/ET RTD (no probe yet — disabled below)
#define CS_TC_IN    8    // MAX31855 (product 269)  — inlet thermocouple

// Set to 1 when the ET RTD probe is installed and filtered
#define RTD_ET_ENABLED  0

// MAX31865 wiring type: MAX31865_2WIRE / MAX31865_3WIRE / MAX31865_4WIRE
#define RTD_WIRES   MAX31865_4WIRE

// PT1000 reference resistor on the 3648 board is 4300 Ω; nominal at 0 °C is 1000 Ω
#define RTD_REF     4300.0f
#define RTD_NOMINAL 1000.0f

// Sensor poll interval (ms) — much shorter than Artisan's sample rate
#define SENSOR_INTERVAL_MS  250

// Robust-read parameters (dimmer EMI tolerance — see hardware/emi.md)
#define RTD_VALID_MIN_C       -20.0f  // plausibility window for accepting a reading
#define RTD_VALID_MAX_C        600.0f
#define RTD_READ_DISAGREE_C    2.0f   // two same-cycle reads differing by more => SPI glitch, hold
#define SENSOR_FAULT_DEBOUNCE  4      // consecutive bad reads before a channel is declared faulted
#define SENSOR_REFAULT_LOG_MS  5000   // min interval between repeated fault-log entries (anti-flood)
#define RTD_MEDIAN_WINDOW      5      // samples in the median filter (set 1 to disable)
#define RTD_REASSERT_MS        5000   // re-assert VBIAS/auto-convert this often (silent-stall guard)

// ---------------------------------------------------------------------------
// DimmerLink I2C addresses and registers
// ---------------------------------------------------------------------------
#define HEAT_ADDR   0x51
#define FAN_ADDR    0x52

#define REG_STATUS  0x00
#define REG_ERROR   0x02
#define REG_LEVEL   0x10
#define REG_CURVE   0x11
#define REG_FREQ    0x20

// ---------------------------------------------------------------------------
// Config
// ---------------------------------------------------------------------------
#define DUTY_STEP               5
#define WS_PORT                 81
#define DL_INIT_RETRY_DELAY_MS  500   // ms between initDL ready-check retries

// Interlock config
#define IL_FAN_MIN      48   // fan level below which heat is always 0
#define IL_FAN_FULL     55   // fan level at or above which heat is unrestricted
#define IL_HEAT_AT_MIN  30   // heat cap (%) when fan is exactly at IL_FAN_MIN (soft mode)

// ---------------------------------------------------------------------------
// Inlet-temperature control (closed loop) — see the control section below and
// work.md for the design. Cooperative for now: controlStep() runs on a fixed
// cadence from loop(); the "seam" keeps the law liftable into a FreeRTOS task
// later without changing the math.
// ---------------------------------------------------------------------------
#define CONTROL_PERIOD_MS   250     // control cadence (Hz = 1000/this); matches sensor poll
#define INLET_SV_MIN_C      0.0f    // plausibility window for an inlet setpoint
#define INLET_SV_MAX_C      300.0f
#define PID_D_FILTER_TC     1.0f    // derivative low-pass time constant (s); 0 = off
#define PID_KAW             0.1f    // anti-windup back-calculation gain (1/s)

// Open-loop step-test autotune (TUNE command). Holds the current heat to measure
// a baseline, applies a heat step, records the inlet response, fits a first-order-
// plus-dead-time (FOPDT) model, and suggests PI gains (SIMC/lambda). Run it with
// fan in the normal range and the roaster roughly steady first.
#define TUNE_STEP_DELTA     15      // default heat step (% points) if none given
#define TUNE_STEP_DELTA_MIN 5
#define TUNE_STEP_DELTA_MAX 40
#define TUNE_BASELINE_MS    8000    // hold current heat this long to measure T0
#define TUNE_MAX_MS         180000  // hard cap on the step-observation phase
#define TUNE_MIN_TEST_MS    10000   // suppress settle detection before this
#define TUNE_SAMPLE_MS      500     // response sampling interval
#define TUNE_MAX_SAMPLES    360     // 180 s at TUNE_SAMPLE_MS
#define TUNE_SETTLE_SECS    15      // response flat this long => settled
#define TUNE_SETTLE_BAND_C  1.0f    // "flat" = max-min within this band (°C)
#define TUNE_MIN_RISE_C     3.0f    // require at least this rise to identify (°C)
#define TUNE_TEMP_ABORT_C   280.0f  // abort the test above this inlet temp (°C)

// ---------------------------------------------------------------------------
// State
// ---------------------------------------------------------------------------
uint8_t requestedHeatLevel = 0;  // commanded heat level
uint8_t heatLevel = 0;           // actual heat level sent to device
uint8_t fanLevel = 0;
bool    interlockSoft = false;   // false = hard (binary), true = soft (linear ramp)

float btTemp  = 0.0;  // bean temp  — MAX31865 PT1000 (°C)
float etTemp  = 0.0;  // exhaust/ET — MAX31865 PT1000 (°C)
float inTemp  = 0.0;  // inlet temp — MAX31855 thermocouple (°C)

String inputBuffer = "";
volatile bool flagDisplayUpdate;

// ---------------------------------------------------------------------------
// Inlet control state
// ---------------------------------------------------------------------------
// Operating mode: MANUAL = heat is whatever OT1 last set; INLET = heat is
// modulated by the closed loop to hold inletSV. Marked volatile because a
// future FreeRTOS control task would read/write these across cores.
enum ctrlMode_t { MODE_MANUAL, MODE_INLET, MODE_TUNE };
volatile ctrlMode_t ctrlMode = MODE_MANUAL;
volatile float       inletSV  = 0.0f;   // inlet setpoint (°C), valid in MODE_INLET

// Autotune progress + last suggestion. Declared here (ahead of processCommand,
// which starts/aborts/applies a tune) rather than beside the tune internals.
enum tunePhase_t { TUNE_IDLE, TUNE_BASELINE, TUNE_STEP };
volatile tunePhase_t tunePhase   = TUNE_IDLE;
bool                 tuneHaveSug = false;   // a suggested-gain set is available
float                tuneSugKp   = 0.0f;    // SIMC "tight" suggestion from last tune
float                tuneSugKi   = 0.0f;

// PID gains — PLACEHOLDERS. The plant has NOT been characterized yet; these are
// deliberately gentle and are not expected to control well. Tune via the step
// test / TUNE routine (work.md phase 3) or live with the PID command before
// relying on closed-loop control. Starts PI-only (Kd = 0) — the inlet TC is
// noisy near the dimmers, so derivative is added only after characterization.
float pidKp = 1.5f;
float pidKi = 0.05f;   // 1/s
float pidKd = 0.0f;

// Feedforward power map (the main robustness-to-airflow mechanism). Physically,
// steady-state heat scales with airflow × temperature rise, so
//   heat_ff = ffK · fan · (SV − ffAmbient)
// One coefficient suffices across the narrow fan band; a fan change moves the
// feedforward immediately and the PID only trims the residual. ffK defaults to 0
// (feedforward off) until calibrated — see the FF command / FF CAL.
float ffK       = 0.0f;    // %·/(fan-level·°C); 0 disables feedforward
float ffAmbient = 25.0f;   // reference/ambient temp the rise is measured from (°C)

// Cooperative-cadence jitter watch (worst control-step late-fire, µs). This is
// the evidence that decides whether a dedicated core is ever warranted — read
// and zeroed via the STAT command. Declared here (ahead of processCommand,
// which reports it) rather than beside the other PID working state below.
volatile uint32_t ctrlMaxJitterUs = 0;

// ---------------------------------------------------------------------------
// Sensors
// ---------------------------------------------------------------------------
static Adafruit_MAX31865 rtdBT(CS_RTD_BT);
static Adafruit_MAX31865 rtdET(CS_RTD_ET);
static Adafruit_MAX31855 tcIN(CS_TC_IN);

// Per-channel fault tracking (debounce + rate-limited logging) and, for the
// RTDs, a median-filter ring buffer and the stall-guard re-assert timer.
struct SensorFaultState {
    uint8_t  badCount;                // consecutive bad reads
    bool     faulted;                 // currently in the (logged) faulted state
    uint32_t lastLogMs;               // last time a fault was logged for this channel
    uint32_t lastReassertMs;          // last VBIAS/auto-convert re-assert (RTD only)
    float    hist[RTD_MEDIAN_WINDOW]; // recent accepted readings (RTD only)
    uint8_t  histHead;                // next write index into hist[]
    uint8_t  histCount;              // valid entries in hist[]
};
static SensorFaultState rtdBTfault = {0, false, 0, 0, {0}, 0, 0};
static SensorFaultState rtdETfault = {0, false, 0, 0, {0}, 0, 0};
static SensorFaultState tcINfault  = {0, false, 0, 0, {0}, 0, 0};

// ---------------------------------------------------------------------------
// Display
// ---------------------------------------------------------------------------
Adafruit_SH1107 display = Adafruit_SH1107(64, 128, &Wire);
#define COL1A     0
#define COL2A     64
#define ROWHEIGHT 8

enum rows_t { ROW1, ROW2, ROW3, ROW4, ROW5, ROW6, ROW7, ROW8 };

// ---------------------------------------------------------------------------
// WebSocket server
// ---------------------------------------------------------------------------
WebSocketsServer webSocket(WS_PORT);

// ---------------------------------------------------------------------------
// Error log (RAM only — no flash writes)
// ---------------------------------------------------------------------------
#define ERR_LOG_SIZE    8
#define ERR_MSG_LEN     64

static char  errLog[ERR_LOG_SIZE][ERR_MSG_LEN];
static uint8_t errHead = 0;   // next write index
static uint8_t errCount = 0;  // total entries stored (capped at ERR_LOG_SIZE)

void logError(const char* msg) {
    strncpy(errLog[errHead], msg, ERR_MSG_LEN - 1);
    errLog[errHead][ERR_MSG_LEN - 1] = '\0';
    errHead = (errHead + 1) % ERR_LOG_SIZE;
    if (errCount < ERR_LOG_SIZE) errCount++;

    Serial.print("[ERR] ");
    Serial.println(msg);

    char buf[ERR_MSG_LEN + 28];
    snprintf(buf, sizeof(buf), "{\"pushMessage\":\"error\",\"data\":\"%s\"}", msg);
    webSocket.broadcastTXT(buf);
}

void sendLog(uint8_t clientNum) {
    uint8_t start = (errCount < ERR_LOG_SIZE) ? 0 : errHead;
    for (uint8_t i = 0; i < errCount; i++) {
        uint8_t idx = (start + i) % ERR_LOG_SIZE;
        char buf[ERR_MSG_LEN + 32];
        snprintf(buf, sizeof(buf), "{\"pushMessage\":\"log\",\"data\":\"%s\"}", errLog[idx]);
        webSocket.sendTXT(clientNum, buf);
    }
    if (errCount == 0) {
        webSocket.sendTXT(clientNum, "{\"pushMessage\":\"log\",\"data\":\"no errors\"}");
    }
}

// ---------------------------------------------------------------------------
// JSON field helpers
// ---------------------------------------------------------------------------

// Extract a quoted string field from a flat JSON object.
// Returns "" if not found.
static String jsonString(const String& json, const char* key) {
    String search = String("\"") + key + "\"";
    int pos = json.indexOf(search);
    if (pos < 0) return "";
    int colon = json.indexOf(':', pos + search.length());
    if (colon < 0) return "";
    int q1 = json.indexOf('"', colon + 1);
    if (q1 < 0) return "";
    int q2 = json.indexOf('"', q1 + 1);
    if (q2 < 0) return "";
    return json.substring(q1 + 1, q2);
}

// Extract a numeric field from a flat JSON object.
// Returns NAN if not found.
static float jsonFloat(const String& json, const char* key) {
    String search = String("\"") + key + "\"";
    int pos = json.indexOf(search);
    if (pos < 0) return NAN;
    int colon = json.indexOf(':', pos + search.length());
    if (colon < 0) return NAN;
    int start = colon + 1;
    while (start < (int)json.length() && json[start] == ' ') start++;
    return json.substring(start).toFloat();
}

// ---------------------------------------------------------------------------
// Forward declarations
// ---------------------------------------------------------------------------
void processCommand(String cmd, int8_t clientNum = -1);
void applyInterlock();
void broadcastStatus();
bool handleArtisanRequest(uint8_t clientNum, const String& msg);
void initSensors();
void updateSensors();
void serviceRtd(Adafruit_MAX31865 &dev, SensorFaultState &st, float &out, const char *name);
float feedforward(float sv, uint8_t fan);
void  engageInlet(float sv);
void  controlStep(uint32_t dtMs);
void  startTune(float deltaPct);
void  abortTune(const char *why);
void  tuneStep(uint32_t dtMs);

// ===========================================================================
// Sensors — init and periodic update
// ===========================================================================

void initSensors() {
    tcIN.begin();

    rtdBT.begin(RTD_WIRES);
    rtdET.begin(RTD_WIRES);

    // Clear any startup faults first, then enable continuous conversion.
    // Order matters: clearFault() resets config bits, so bias and autoConvert must come after.
    rtdBT.clearFault();
    rtdBT.enableBias(true);
    rtdBT.autoConvert(true);
#if RTD_ET_ENABLED
    rtdET.clearFault();
    rtdET.enableBias(true);
    rtdET.autoConvert(true);
#endif

    Serial.println("Sensors initialized");
}

// Median of the valid entries in a channel's history ring (order doesn't matter).
static float rtdMedian(const SensorFaultState &st) {
    float tmp[RTD_MEDIAN_WINDOW];
    uint8_t n = st.histCount;
    for (uint8_t i = 0; i < n; i++) tmp[i] = st.hist[i];
    for (uint8_t i = 1; i < n; i++) {          // insertion sort (n is tiny)
        float key = tmp[i];
        int8_t j = i - 1;
        while (j >= 0 && tmp[j] > key) { tmp[j + 1] = tmp[j]; j--; }
        tmp[j + 1] = key;
    }
    return tmp[n / 2];
}
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
void loop() {
    webSocket.loop();

    // Serial commands
    while (Serial.available()) {
        char c = (char)Serial.read();
        if (c == '\n') {
            processCommand(inputBuffer, -1);
            inputBuffer = "";
        } else if (c != '\r') {
            if (inputBuffer.length() < 32) inputBuffer += c;
        }
    }

    // Sensor update (every SENSOR_INTERVAL_MS)
    static uint32_t lastSensorPoll = 0;
    uint32_t now = millis();
    if (now - lastSensorPoll >= SENSOR_INTERVAL_MS) {
        lastSensorPoll = now;
        updateSensors();
    }

    // Inlet control step (fixed cadence; the controlStep() seam). Uses the
    // measured interval so cooperative jitter doesn't bias the integral, and
    // records the worst late-fire as evidence on whether a dedicated core is
    // ever needed (read via STAT). controlStep() is a no-op in MODE_MANUAL.
    static uint32_t lastCtrl = 0;
    uint32_t ctrlDt = now - lastCtrl;
    if (ctrlDt >= CONTROL_PERIOD_MS) {
        if (lastCtrl != 0 && ctrlDt > CONTROL_PERIOD_MS) {
            uint32_t jitterUs = (ctrlDt - CONTROL_PERIOD_MS) * 1000UL;
            if (jitterUs > ctrlMaxJitterUs) ctrlMaxJitterUs = jitterUs;
        }
        lastCtrl = now;
        controlStep(ctrlDt);
    }

    // Periodic DimmerLink error poll (every 5 s)
    static uint32_t lastErrorPoll = 0;
    if (now - lastErrorPoll >= 5000) {
        lastErrorPoll = now;
        checkDLError(HEAT_ADDR);
        checkDLError(FAN_ADDR);
    }

    // Recheck interlock every loop in case fan level changed outside OT2
    applyInterlock();

    // Display
    if (flagDisplayUpdate) {
        display.clearDisplay();
        displayUpdate();
        flagDisplayUpdate = false;
    }
}

// ===========================================================================
// Version history
// ---------------------------------------------------------------------------
// v0.5.0  2026-06-29  Feedforward power map (robustness to airflow changes):
//                     heat_ff = ffK · fan · (SV − ffAmbient), summed into the
//                     control law so a fan change moves heat immediately and the
//                     PID only trims the residual. FF command: report / set ffK /
//                     FF AMB <degC> / FF CAL (auto-calibrate ffK from the current
//                     steady point) / FF OFF. Defaults off (ffK = 0). Already
//                     consistent with the bumpless engage-seed and anti-windup,
//                     which referenced feedforward() from the start.
// v0.4.0  2026-06-29  Open-loop step-test autotune (TUNE command). Holds the
//                     current heat to measure a baseline, applies a heat step,
//                     samples the inlet response, fits an FOPDT model (two-point
//                     28.3%/63.2% method) and suggests PI gains via SIMC at two
//                     robustness levels (tight/conservative). New MODE_TUNE; the
//                     step runs through applyInterlock() so inadequate airflow
//                     aborts it, with over-temp and operator-override aborts too.
//                     TUNE [pct] / TUNE ABORT / TUNE APPLY. Results broadcast as
//                     a "tune" push message. No external library — identification
//                     and tuning are inline (see work.md phase 3).
// v0.3.0  2026-06-29  Inlet-temperature closed-loop control (cooperative). New
//                     MODE_INLET: controlStep() modulates heat from measured
//                     inlet temp with a PI(D) loop — derivative-on-measurement,
//                     back-calculation anti-windup against the *applied* (post-
//                     interlock) heat, bumpless engage. Commands: INLET <degC> /
//                     INLET OFF, PID (report/set gains live), STAT (control
//                     jitter watch). OT1 is an instant manual override. Mode +
//                     setpoint added to the status broadcast and OLED row 5.
//                     Gains are untuned placeholders. Feedforward + sTune TUNE
//                     routine are the next phases (see work.md). The control law
//                     is isolated in controlStep() so it can later move to a
//                     pinned FreeRTOS task unchanged.
// v0.2.1  2026-06-28  RTD read robustness: periodic VBIAS/auto-convert re-assert
//                     (guards against a silently-stalled converter), and a median
//                     filter over recent samples (rejects single-sample spikes).
//                     Also: BT mapped to the connected board (CS_RTD_BT=10); the
//                     empty board is ET (CS=9), gated off via RTD_ET_ENABLED.
// v0.2.0  2026-06-28  Sensor integration: 2x MAX31865 PT1000 (BT/ET) + MAX31855
//                     K-type (inlet), 3-channel Artisan output (BT/ET/IN),
//                     temps on OLED. Robust RTD reads — same-cycle glitch
//                     rejection, fault debounce, hold-last-good, rate-limited
//                     fault logging. ET RTD behind RTD_ET_ENABLED gate (no probe
//                     yet). BT/ET CS pins swapped to match wiring.
// v0.1.0  (baseline)  Dual DimmerLink heat/fan control, WebSocket + Artisan
//                     protocol, plain-text/serial commands, OLED status, fan
//                     interlock (hard/soft), RAM error log.
// ===========================================================================

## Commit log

2026-06-07 Initial commit — ESP32 air roaster controller
    WebSocket-based control of heat and fan via DimmerLink I2C dimmers.
    Includes interlock safety, RAM-based error log, and OLED display support.
    [airRoaster_v01.ino]
2026-06-08 Add Artisan settings file for airRoaster v01
    WebSocket device (id 111), port 81, BT/ET channels, fan/heat sliders.
    Replace <device-ip> with the ESP32's IP before importing.
2026-06-22 Update README: hardware details, startup sequence, interlock docs
    - Add specific board/product links and hardware details (ESP32-S3 Feather,
    FeatherWing OLED, RBDimmer DimmerLink, heater element, Ametek blower)
    - Reorder startup sequence: DimmerLink init now before WiFi
    - Replace FAN_INTERLOCK_THRESHOLD with IL_* constants in config table
    - Add DL_INIT_RETRY_DELAY_MS constant
    - Document hard vs soft interlock modes with breakpoint table
    - Add IL command to command table
    - Update display ROW4 layout with interlock status values
    - Update status broadcast schema (ilCap/ilSoft replacing interlock bool)
2026-06-29 Add RTD/TC sensor robustness, EMI docs, and Artisan tooling (v0.2.1)
    Firmware (v0.2.1):
    - Robust RTD reads: same-cycle SPI glitch rejection, fault debounce,
    hold-last-good, median filter, and periodic VBIAS/auto-convert re-assert
    to guard against a silently-stalled MAX31865.
    - Map BT to the connected MAX31865 (CS_RTD_BT=10); empty ET board gated
    off via RTD_ET_ENABLED.
    - Firmware version string (FW_VERSION), version on the OLED, and an
    in-file changelog.
    Docs:
    - hardware/emi.md: dimmer-noise diagnosis and mitigation writeup
    (fault decoding, source suppression, shielding, capacitor plan, SPI).
    - hardware/pins.md + pins.pdf: ESP32-S3 Feather pin/bus map.
    - hardware/pcb_mounts: senso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
    [adafruit269_mount.3mf, adafruit3263_mount.3mf, adafruit3648_mount.3mf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]
2026-06-29 Add open-loop step-test autotune (TUNE, v0.4.0)
    New MODE_TUNE runs an open-loop step test to characterize the inlet plant and
    suggest PI gains, so the closed loop can be tuned without external tools:
    - Holds current heat to measure a baseline, steps heat, samples the inlet
    response, fits an FOPDT model (two-point 28.3%/63.2% method), and suggests
    PI gains via SIMC at two robustness levels (tight/conservative).
    - Process gain uses the actual post-interlock heat delta.
    - The step runs through applyInterlock(), so inadequate airflow aborts the test;
    also aborts on over-temp (>280C) and on any OT1/INLET/TUNE ABORT.
    - Commands: TUNE [pct] / TUNE ABORT / TUNE APPLY (applies the tight sugges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
    [airRoaster_v01.ino]
2026-06-30 Rename project airRoaster_v01 -> airRoaster
    Drop the "v01" from the project name everywhere:
    - Folder airRoaster_v01/ -> airRoaster/ and sketch airRoaster_v01.ino ->
    airRoaster.ino (Arduino requires the folder and .ino names to match).
    - Settings files airRoaster_v01.aset -> airRoaster.aset (root and artisan/),
    including their internal profilepath/settingspath/roastertype_setup.
    - In-text references across README.md, hardware/emi.md,
    artisan/artisan_config_context.md, and verify.sh.
    Firmware version strings (FW_VERSION, version history) are unchanged — only the
    project name was touched. Local .claude/settings.local.json keeps its historical
    permission paths and is intentionally left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
    [airRoaster.ino]
2026-06-30 Add command input + commissioning panel to web console
    Rename artisan/log.html -> dashboard.html and expand it from a
    log viewer into a control surface: free-text command box, quick
    buttons for the no-arg bring-up commands, and a guided
    "Commissioning sequence" panel that walks flash → sanity → TUNE →
    feedforward → close-loop in order with value fields prefilled.
    Document the same sequence in a README Commissioning section and
    update the dashboard references in hardware/emi.md.
2026-06-30 Add Artisan inlet-SV background generator and update profiles
    make_inlet_background.py builds an Artisan background .alog whose INLET
    setpoint curve lives in an extra-device channel (B3), for use as the SV
    source in Artisan's PID "Follow Background" mode. Monotonic PCHIP-style
    interpolation through start/dry/FC/drop anchors, no third-party deps.
    Includes generated background profiles and updated Artisan settings.
2026-06-30 verify.sh: case-correct sketch path, harden upload port detection
    realpath canonicalizes the folder case — macOS's case-insensitive cd can
    hand arduino-cli a lowercase folder name it won't match against
    airRoaster.ino. Upload now prefers the FQBN-matched port and falls back to
    a USB serial port, never matching the Bluetooth ports that also report
    protocol "serial".
